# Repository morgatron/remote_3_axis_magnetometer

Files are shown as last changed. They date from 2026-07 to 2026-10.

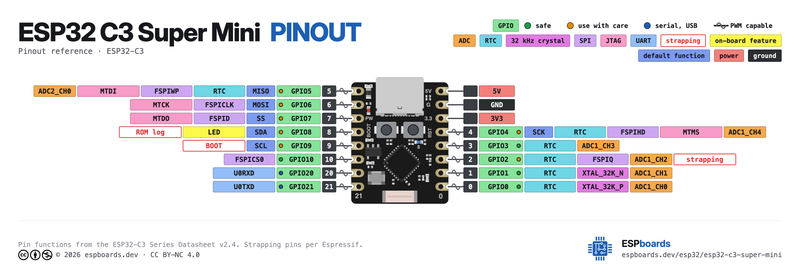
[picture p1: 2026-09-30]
docs/datasheets/supermini_diagram.png

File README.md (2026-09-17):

# Remote 3-Axis Magnetometer Acquisition System

A high-resolution, battery-powered remote magnetic field monitoring ecosystem supporting PNI RM3100 digital SPI magnetometers and FLC100 analog fluxgates (sampled via 24-bit TI ADS131E08 ADC).

Features universal field sensor firmware, multi-protocol receiver gateway firmware (**LoRa**, **ESP-NOW**, **BLE Coded PHY**, **WiFi UDP**), an edge relay service, a PySide6 desktop plotting app, and a central server with a real-time Web GUI dashboard.

---

## 📖 User Documentation

Complete user documentation is available in the [`docs/`](docs/) directory:

- [**Documentation Index (`docs/README.md`)**](docs/README.md)
- [**1. Getting Started Guide (`docs/1_GETTING_STARTED.md`)**](docs/1_GETTING_STARTED.md)
- [**2. Firmware & Power Optimization Guide (`docs/2_FIRMWARE_AND_POWER_GUIDE.md`)**](docs/2_FIRMWARE_AND_POWER_GUIDE.md)
- [**3. Wireless & Field Testing Guide (`docs/3_WIRELESS_AND_FIELD_TESTING.md`)**](docs/3_WIRELESS_AND_FIELD_TESTING.md)
- [**4. Central Server & Dashboards Guide (`docs/4_CENTRAL_SERVER_AND_DASHBOARDS.md`)**](docs/4_CENTRAL_SERVER_AND_DASHBOARDS.md)
- [**Active Device Profiles Reference (`IN_USE_PROFILES.md`)**](IN_USE_PROFILES.md)
- [**Minimal End-to-End Testing Setup (`TESTING_SETUP.md`)**](TESTING_SETUP.md)
- [**AI Architecture & Development Guide (`AI.md`)**](AI.md)

---

## 🚀 Quickstart

```bash
# 1. Clone & activate Conda environment
git clone https://github.com/morgatron/remote_3_axis_magnetometer.git
cd remote_3_axis_magnetometer
conda env create -f environment.yml
conda activate rm3100

# 2. Start Central Data Server
cd central_service && python server.py
# Open http://localhost:8000

# 3. Flash Heltec V4 Gateway Node
pio run -e heltec_v4_receiver -t upload --upload-port /dev/ttyACM1

# 4. Flash Heltec V4 Field Sensor Node
pio run -e heltec_v4_sensor -t upload --upload-port /dev/ttyACM0
```

---

## 🛠 Supported Hardware

| Hardware Board | Microcontroller | Radio Transceivers | Sensor Interfaces |
| :--- | :--- | :--- | :--- |
| **Heltec WiFi LoRa 32 V4** | ESP32-S3 (Dual-core LX7 @ 240 MHz) | Sub-GHz SX1262 LoRa (+22 dBm), Wi-Fi, BLE 5.0 | PNI RM3100 / ADS131E08 ADC |
| **ESP32-C6 RISC-V PCB** | ESP32-C6 (RISC-V @ 160 MHz) | Wi-Fi 6 (802.11ax), BLE 5.3 Coded PHY, 802.15.4 | PNI RM3100 / ADS131E08 ADC |
| **ESP32-C3 RISC-V PCB** | ESP32-C3 (RISC-V @ 160 MHz) | Wi-Fi 4, BLE 5.0 | PNI RM3100 / ADS131E08 ADC |

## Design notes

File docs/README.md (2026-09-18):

# Remote 3-Axis Magnetometer System — Documentation

Welcome to the documentation for the **Remote 3-Axis Magnetometer Acquisition System**.

---

## 📚 Core Manuals

1. [**1. Getting Started Guide**](1_GETTING_STARTED.md)
   - System architecture overview
   - Hardware pinouts & wiring (ESP32-C3 Supermini, Seeed XIAO ESP32-C6, Heltec V4, RM3100, FLC100)
   - PlatformIO build environments & flashing commands
   - Provisioning wizard (`provision_node.py` & `provision_receiver.py`)

2. [**2. Firmware & Power Optimization Guide**](2_FIRMWARE_AND_POWER_GUIDE.md)
   - Binary batching architecture (`SensorBatchPacket` with centi-degree temperature & $V_{bat}$)
   - Interactive Serial CLI command reference for Sensor and Receiver nodes
   - Multi-protocol output modes (BLE Coded PHY, LoRa SX1262, ESP-NOW, Wi-Fi UDP)
   - Low-power techniques (Slotted Rendezvous 350ms lead time, DFS 40MHz sleep, OLED auto-sleep)

3. [**3. Wireless & Field Testing Guide**](3_WIRELESS_AND_FIELD_TESTING.md)
   - Real-time phone monitoring using the **nRF Connect** app
   - Understanding signal strength: Sensor-to-Gateway RSSI vs. Gateway-to-Phone RSSI
   - Laptop Python client (`scripts/ble_monitor.py`) with real-time diagnostic decoding
   - Wireless range testing & link margin evaluation (`scripts/rssi_monitor.py`)

4. [**4. Central Server & Dashboards Guide**](4_CENTRAL_SERVER_AND_DASHBOARDS.md)
   - Self-contained FastAPI Central Server (`server.py`) and operations manager (`manage.sh`)
   - Docker Compose deployment & port mappings
   - REST API endpoints, WebSockets, API Key authentication, CSV & HDF5 export
   - Desktop PySide6 application (`desktop_app/main.py`)

---

## 📦 Legacy Archives
Older guides and historical references are preserved in [`docs/archive_legacy_docs/`](archive_legacy_docs/).

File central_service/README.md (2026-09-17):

# Magnetometer Central Service

A lightweight, future-proof time-series ingestion server, WebSockets live streaming hub, and real-time Web GUI dashboard for distributed 3-axis magnetometer sensor networks.

Designed to run seamlessly on **Raspberry Pi 4**, **Old Laptops (Linux/Ubuntu)**, or **Docker** behind residential home Wi-Fi networks (NAT/CGNAT).

---

## ⚡ Quick Start (1-Line Installer)

On your target machine (Raspberry Pi or Laptop):

```bash
cd central_service
sudo ./install.sh
```

The installer will:
1. Install Python packages & SQLite.
2. Configure `.env` settings.
3. Install and start `magnetometer-server` and `magnetometer-gateway` as auto-restarting **systemd background services**.
4. Apply hardware tweaks (disables laptop lid-close sleep and Wi-Fi power savings).
5. Print your local LAN access URLs (`http://192.168.x.x:8000`).

---

## 🛠️ Management CLI (`./manage.sh`)

Manage the server with intuitive commands:

```bash
./manage.sh status     # Show health, memory, database file size, and record count
./manage.sh logs       # Live stream colorized logs
./manage.sh restart    # Restart services
./manage.sh stop       # Stop services
./manage.sh backup     # Safe online SQLite backup into backups/
./manage.sh export csv # Quick CLI telemetry export to CSV (or parquet, npz)
./manage.sh test       # Inject synthetic test reading to verify the pipeline
```

---

## 🌐 Remote Access & Residential NAT / CGNAT (`./remote_access.sh`)

If your server sits behind a home Wi-Fi router with dynamic IPs or Carrier-Grade NAT (CGNAT), run the interactive assistant:

```bash
./remote_access.sh
```

- **Option 1 (Cloudflare Tunnels - Recommended)**: Outbound tunnel to Cloudflare Edge. Zero ports opened on router, free automatic SSL/HTTPS, and remote sensor nodes (ESP32/Pi) stream data with **zero VPN or client software required**.
- **Option 2 (Tailscale Mesh VPN)**: Private encrypted WireGuard mesh for administrative access between personal machines.
- **Option 3 (Port Forwarding & DDNS Guide)**: Traditional port forwarding walkthrough for non-CGNAT ISPs.
- **Option 4 (NAT / CGNAT Diagnostics)**: Check if your ISP uses CGNAT (`100.64.0.0/10`).

---

## 🐳 Docker Deployment

```bash
# Start server in background
docker compose up -d

# Start server + UDP edge gateway
docker compose --profile all up -d
```

---

## 📚 Detailed Documentation

- [Central Server & Dashboards Guide (`docs/4_CENTRAL_SERVER_AND_DASHBOARDS.md`)](../docs/4_CENTRAL_SERVER_AND_DASHBOARDS.md)
- [Central Server Architecture & API Specification (`central_service/AI.md`)](AI.md)
- [Historical Legacy Server Setup Guide (`docs/archive_legacy_docs/SERVER_SETUP_GUIDE.md`)](../docs/archive_legacy_docs/SERVER_SETUP_GUIDE.md)
- [Historical NAT & Remote Access Guide (`docs/archive_legacy_docs/NAT_AND_REMOTE_ACCESS.md`)](../docs/archive_legacy_docs/NAT_AND_REMOTE_ACCESS.md)
- [Historical Secrets & Security Guide (`docs/archive_legacy_docs/SECRETS_AND_SECURITY.md`)](../docs/archive_legacy_docs/SECRETS_AND_SECURITY.md)

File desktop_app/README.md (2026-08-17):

# 3-Axis Magnetometer Visualizer Desktop App

This PySide6 desktop application provides a modular, real-time visualization, PSD spectral analysis, and HDF5 scientific data acquisition platform for distributed 3-axis magnetometers.

## Prerequisites
- Python 3.8+ (included in the `rm3100` Conda environment)
- Microcontroller connected via USB Serial CDC or broadcasting over Wi-Fi UDP (Port 9876).

## Installation
```bash
cd desktop_app
pip install -r requirements.txt
```

## Usage
```bash
python main.py
```
1. Select the correct **Port** (e.g. `/dev/ttyACM0` or `WIFI_UDP (Port 9876)`).
   - Tip: Select `MOCK_SENSOR` to run in simulated mode without physical hardware.
2. Click **Connect**.
3. Use **Stream ON** / **Stream OFF** to control MCU streaming.
4. Switch to the **PSD Analysis** tab to view real-time Power Spectral Density.
5. Click **Provision Node...** to configure remote network and measurement parameters over Serial CLI.

## Modular Architecture

The desktop application is divided into self-contained, decoupled subsystems:

```
desktop_app/
├── main.py                  # Lightweight orchestrator MainWindow (< 300 lines)
├── core/
│   ├── data_buffer.py       # Thread-safe circular ring buffer with downsampling
│   └── hdf5_recorder.py     # Chunked Gzip-compressed HDF5 streaming recorder
├── widgets/
│   ├── time_series_plot.py  # PyQtGraph 3-axis plotting widget & real-time filters
│   ├── psd_plot.py          # Welch PSD spectral analysis widget
│   ├── stats_panel.py       # Real-time channel means display
│   ├── acquisition_sidebar.py # HDF5 recording & dynamic sensor controls
│   └── provision_dialog.py  # Modal dialog for ESP32 NVS provisioning
├── serial_worker.py         # Background serial reader thread
├── udp_worker.py            # Background UDP packet receiver thread
└── hdf5_loader.py           # Helper script for loading saved HDF5 files
```

## Loading Saved HDF5 Data

Saved acquisitions are stored in compressed scientific HDF5 (`.h5`):

```python
from hdf5_loader import load_hdf5_dataset

data, attrs = load_hdf5_dataset("acquisition.h5")
print(f"Loaded {len(data['time_s'])} samples recorded over {attrs.get('duration_seconds', 0):.2f}s")
print(f"X mean: {data['x'].mean():.2f} nT, Y mean: {data['y'].mean():.2f} nT, Z mean: {data['z'].mean():.2f} nT")
```

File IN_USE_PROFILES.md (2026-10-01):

The device profiles currently in use are the following, with labels to refer to them.
All use battery power unless specified otherwise

- Heltec V4 sensor (label: SPRINGBANK)
    - connected to FLC100.
    - transmits over LoRa only
- Heltec V4 Receiver (label: ROOF)
    - Receives over LoRa (SX1262 Sub-GHz, batches from SPRINGBANK)
    - Connects directly to campus enterprise Wi-Fi (ANU-Secure WPA2-Enterprise 802.1X PEAP or standard PSK)
    - Synchronizes atomic UTC time via NTP (pool.ntp.org) and reconstructs millisecond-accurate ISO 8601 sample timestamps
    - Egress: Direct HTTP POST JSON batch forwarding to Central Server (`/api/v1/telemetry/batch` with `X-API-Key`)
    - Concurrent USB Serial CDC output preserved for local monitoring and CLI configuration
    - wired power
- Seeed Studio Xiao ESP32-C6 Sensor (label: CREEK)
    - connected to FLC100
    - communicates over BLE with coded PHY
- Seeed Studio Xiao ESP32-C6 Sensor (label: CREEK_TEST)
    - connected to FLC100
    - communicates over BLE with coded PHY (node ID: _CREEK)
- Seed Studio Xiao ESP32-C6 (label: CREEK_GATEWAY)
    - Receives using BLE coded PHY only
    - relays data to host computer using BLE
- Supermini ESP32-C3 Receiver (label: SUPERMINI_GATEWAY)
    - Receives using BLE Coded PHY only (Slotted Rendezvous: 350 ms lead time, 1000 ms fallback window, immediate discovery lock)
    - Dedicated Coded PHY active scanning (`pScan->setPhy(SCAN_CODED)`) ensuring 100% duty cycle reception and instant `AUX_SCAN_REQ` hardware ACKs
    - Cadence tracking invariant to backlog (`nominalPeriod = 10000 ms`, never scales with `sample_count`)
    - Relays data to host computer using BLE Extended Advertising (1M PHY, 200 ms burst)
    - USB-CDC disabled on boot (`ARDUINO_USB_MODE=0`, `ARDUINO_USB_CDC_ON_BOOT=0`) for minimum quiescent power draw
    - Wi-Fi radio powered off (`WiFi.mode(WIFI_OFF)`, ~80 mA saved)
    - Dynamic Frequency Scaling (DFS): 40 MHz during radio sleep (~10–12 mA), 80 MHz during burst/RX
    - Target current: ~12 - 15 mA average (~65 - 80 hours on 1,000 mAh LiPo / ~8 - 10 days on 3,000 mAh 18650)
- Seeed Studio Xiao ESP32-C6 Sensor (label: LAB_BENCH)
    - connected to FLC100
    - wired USB power (used for lab bench magnetic measurements)
    - communicates with desktop GUI host computer over USB Serial only (`MODE SERIAL`, 921600 baud)
    - 100 Hz output streaming rate (1 kHz raw ADS131E08 ADC data downsampled by a factor of 10)
    - not for use with wireless gateway or central server (BLE/LoRa/WiFi radios disabled)
- Supermini ESP32-C3 Sensor (label: LYNEHAM1)
    - connected to RM3100 3-axis magneto-inductive sensor
    - Cycle count set to 600 on X, Y, Z (gain: 221.76 LSB/µT, resolution: 4.51 nT/LSB)
    - Continuous sampling at ~40 Hz (`TMRC 0x96`), downsampled 40x via boxcar averaging to 1.00 Hz
    - `I2CEN` held LOW via GPIO 5 virtual ground to force hardware SPI mode
    - wired USB power (plugs directly into host computer)
    - communicates with host computer over USB Serial only (`MODE SERIAL`, 921600 baud, 1 Hz CSV output)
    - not for use with wireless gateway or central server (BLE/LoRa/WiFi radios disabled)

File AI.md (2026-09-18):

# Overview

This repository contains firmware, an edge gateway, a PySide6 desktop visualization application, and a lightweight central data server (`central_service`) for an ESP32-based 3-axis magnetometer acquisition system.

A single universal firmware binary supports two sensor configurations via NVS dynamic provisioning:
1. **PNI RM3100**: High-resolution digital SPI magnetometer (Hardware REVID `0x22`).
2. **FLC-100 Analog Fluxgate Array**: Differential analog front-end sampled via an external **TI ADS131E08 24-bit 8-channel SPI ADC** (VREF = 2.4V, 2.0 MHz SPI clock).

The system streams calibrated 6-column magnetic field data in **Nanotesla (nT)** over Serial (921.6 kbaud), WiFi UDP (Port 9876), or Bluetooth 5.0 LE (Nordic UART Service) at up to **1 kSPS** (600 Hz max for RM3100).

---

## Key System Architecture Features

1. **MCU On-Board Scaling**:
   - The ESP32 calculates scale factors on-board: $\text{Gain}(N_C) = 0.3671 \times N_C + 1.5\ \text{LSB}/\mu\text{T}$.
   - Converting raw counts directly to physical Nanotesla ($\text{nT}$) before output ensures the reported magnitude $|\mathbf{B}|$ remains invariant across dynamic cycle count ($N_C \in [50, 400]$) and rate changes.

2. **Self-Healing Hardware Watchdog**:
   - Detects SPI bus stalls or missed `/DRDY` interrupts (e.g. from physical bumps or power glitches) within **500 ms**.
   - Automatically detaches interrupts, resets SPI CS pins, re-probes and re-initializes the sensor ASIC, clears hardware latches, and resumes streaming without requiring a manual reboot.

3. **Central Data Server (`central_service/`)**:
   - Single-file FastAPI + SQLite (WAL mode) time-series server designed for 10–50 distributed nodes on a Raspberry Pi (< 30 MB RAM).
   - Real-time Web GUI (`http://localhost:8000`) with live WebSockets (`/ws/live`).
   - Versioned API (`/api/v1/...`) with export support for **CSV**, **Apache Parquet (`.parquet`)**, **NumPy (`.npz`)**, and **JSON**.
   - Built-in server-side downsampling (`downsample_sec=60`) for multi-month trend analysis.

4. **Unified Edge Gateway (`central_service/gateway.py`)**:
   - Listens concurrently for WiFi UDP (port 9876), BLE 5.0 (Nordic UART Service), and USB Serial streams.
   - Includes a thread-safe **Store-and-Forward Buffer** to queue telemetry during network outages and flush batch payloads upon reconnection.

5. **PySide6 Desktop Application (`desktop_app/main.py`)**:
   - Provides real-time multi-axis time-series plotting, Welch PSD spectral analysis, device provisioning, and Gzip-compressed HDF5 (`.h5`) logging.

6. **Edge Arrival Timestamping & Monotonic Epoch Tracking (`NodeEpochTracker`)**:
   - Field nodes stream raw microsecond uptimes (`timestamp_us`) without requiring battery-backed RTC chips or NTP client stacks.
   - Upon packet arrival at the edge gateway (`gateway.py` / `ble_monitor.py`), `NodeEpochTracker` locks and tracks the node's monotonic boot epoch ($T_{\text{epoch}} = T_{\text{wall}} - t_{\mu\text{s}} \times 10^{-6}$) against the host's NTP-synchronized UTC clock.
   - For multi-sample batches and backlog recovery dumps after outages, `NodeEpochTracker` maps each sample's `timestamp_us` directly to its true historical UTC moment, preventing timestamp clustering or collisions during high-speed backlog catch-up bursts while smoothly filtering microsecond crystal frequency drift (~15 ppm).

7. **Modular Telemetry Ring Buffer (`include/TelemetryRingBuffer.h`)**:
   - Encapsulates 10-minute (600-sample) disconnect backlog storage into a thread-safe, self-contained C++ class.
   - Automatically handles FIFO eviction during prolonged outages, batch packaging for Coded PHY BLE Extended Advertising bursts, and hardware `AUX_SCAN_REQ` ACK confirmation flushes.
   - Standardized across all target boards on **NimBLE-Arduino 2.2.0** for BLE 5.0 Long Range Coded PHY support.

8. **Unified Multi-Protocol Receiver Interface (`src/receiver/ITelemetryReceiver.h`)**:
   - Abstracts all physical receiver drivers (`BLEReceiver`, `ESPNowReceiver`, `UDPReceiver`, `LoRaReceiver`) behind a polymorphic `ITelemetryReceiver` interface.
   - Decouples receiver initialization (`begin()`) and non-blocking polling (`poll()`) from the main loop thread, ensuring zero-blocking execution (< 25 $\mu$s per tick).
   - Centralizes CSV formatting (`formatCsvLine()`) and string parsing (`parseCsvLine()`) directly inside `TelemetryItem` to eliminate code duplication across protocols.

---

---

## Hardware Management Architecture (`include/board_config.h` & `platformio.ini`)

All hardware target boards are managed through a **centralized, single-source-of-truth configuration design**:

1. **Centralized Board Header (`include/board_config.h`)**:
   - Maps MCU preprocessor macros to physical board pinouts (Magnetometer SPI, LoRa SPI, status LEDs, and power rails).
   - Provides `initBoardPower()` to control hardware power gating rails (e.g. driving Heltec Vext GPIO 36 `LOW` during setup).
   - Abstracts hardware differences away from firmware business logic (`main.cpp` and `receiver_main.cpp`).

2. **DRY PlatformIO Configuration (`platformio.ini`)**:
   - Root `[env]` base section defines common parameters (`framework = arduino`, `monitor_speed = 921600`, upload flags, and native USB CDC defines).
   - Target environments inherit from `[env]` and select their role via `build_src_filter`:
     - **Field Sensor Node**: `build_src_filter = +<*> -<receiver/*>`
     - **Receiver & Gateway Node**: `build_src_filter = +<receiver/*>`

### Supported Hardware Pinout Reference Table

| Target Hardware Board | PlatformIO Env (`Sensor` / `Receiver`) | Sensor SCK | Sensor MOSI | Sensor MISO | Sensor CS | Sensor DRDY | LoRa CS / DIO1 / RST / BUSY | Vext Rail |
| :--- | :--- | :--- | :--- | :--- | :--- | :--- | :--- | :--- |
| **ESP32-C3 RISC-V PCB** | `esp32-c3-devkitm-1` / `esp32c3_receiver` | GPIO 6 | GPIO 7 | GPIO 2 | GPIO 10 | GPIO 3 | GPIO 5 / 4 / 14 / 15 | N/A |
| **ESP32-C6 Wi-Fi 6 PCB** | `esp32-c6-devkitc-1` / `esp32c6_receiver` | GPIO 6 | GPIO 7 | GPIO 2 | GPIO 10 | GPIO 3 | GPIO 5 / 4 / 14 / 15 | N/A |
| **Heltec V4 (ESP32-S3 + SX1262)** | `heltec_v4_sensor` / `heltec_v4_receiver` | GPIO 41 | GPIO 42 | GPIO 40 | GPIO 39 | GPIO 38 | GPIO 8 / 14 / 12 / 13 | GPIO 36 |
| **Legacy ESP32 Dev (WROOM)** | `esp32dev` / `esp32dev_receiver` [Deprecated] | GPIO 18 | GPIO 23 | GPIO 19 | GPIO 5 | GPIO 4 | GPIO 5 / 4 / 14 / 15 | N/A |

### How to Add a New Hardware Board
To support a new board (e.g. ESP32-S3 DevKit or Raspberry Pi Pico 2 W):
1. Add a `#elif defined(YOUR_BOARD)` block in [`include/board_config.h`](file:///home/morgan/Gropbox/SMACT2026/remote_3_axis_magnetometer/include/board_config.h) defining SPI CS, SCK, MOSI, MISO, DRDY, and LoRa pins.
2. Add sensor and receiver target environment blocks in [`platformio.ini`](file:///home/morgan/Gropbox/SMACT2026/remote_3_axis_magnetometer/platformio.ini) with `-D YOUR_BOARD`.

---

## Data Stream Format & CLI Reference

### 6-Column CSV Data Stream
`device_id,timestamp_us,x_nT,y_nT,z_nT,status`
- **`device_id`**: Node identifier string (e.g. `SENSOR_01` or MAC-derived `NODE_686F80`).
- **`timestamp_us`**: MCU uptime in microseconds (`uint64_t`).
- **`x_nT, y_nT, z_nT`**: Calibrated 3-axis magnetic field in Nanotesla ($\text{nT}$).
- **`status`**: 24-bit hex SPI status word (e.g., `C00000`).

### Interactive CLI Commands (Serial / UDP / BLE)

| Command | Description |
| :--- | :--- |
| `HELP` / `STATUS` | Display CLI help / Query Device ID, sensor model, rate code, BLE batch size, and status |
| `STREAM ON` / `OFF` | Enable / disable continuous telemetry stream |
| `ID <name>` | Configure custom Device ID / Node name (saves to NVS Flash) |
| `SENSOR <FLC100\|RM3100\|MOCK>` | Set active sensor model (`MOCK` = synthetic range test telemetry) |
| `RATE <hex>` | Set rate code (`0x95` = 75 Hz, `0x94` = 150 Hz, `0x93` = 300 Hz, `0x92` = 600 Hz) |
| `CYCLE <int>` | Set RM3100 oscillation cycle count (e.g. `CYCLE 200`) |
| `BATCH <1-10>` | Set BLE burst size (`1` = instant 1 Hz, `10` = 10s low-power mode; saved to NVS) |
| `MODE <SERIAL\|WIFI\|BLE\|BOTH>` | Route stream to USB Serial, WiFi UDP, BLE Long Range, or both |

---

## Low-Power LE Coded PHY Batching & Hardware ACK Architecture (Primary Mode)

> [!IMPORTANT]
> **Canonical Primary Protocol Constraint**: The **Low-Power Bluetooth 5.0 LE Coded PHY Batching Protocol with Hardware ACKs and Disconnect Ring Buffering** is the canonical primary operational mode for field sensor nodes. Future edits MUST preserve this low-power ACK architecture.

1. **BLE 5.0 LE Coded PHY (Long Range S=8)**:
   - Extended Advertising using **Coded PHY S=8 (125 kbps)** provides **+12 dB sensitivity gain** (~4x range multiplier over standard BLE) at **+15 dBm Max Power**.

2. **Configurable Batch Bursting (`BATCH <1-10>`)**:
   - The BLE radio remains **100% OFF for 9.7 seconds** out of every 10 seconds (`BATCH 10`).
   - At burst time, `pAdvertising->start(0, 30)` powers on the radio for **300 ms** (30 x 10ms units) to broadcast a 139-byte Extended Advertising payload (`SensorBatchPacket`) containing up to 10 compact 3-axis samples over Coded PHY S=8.
   - **Transmission-Complete Auto-Stop**: When the 300ms burst completes, the `onStopped` hardware callback fires, setting `g_lastBatchAcked = true` and powering **OFF** the radio until the next 10-second window.
   - **RF Duty Cycle**: Reduces active RF transmission duty cycle to **< 0.5%**, extending battery life to **35–45 days** on a 1000 mAh LiPo.

3. **Hardware `AUX_SCAN_REQ` ACKs & 10-Minute Disconnect Ring Buffer**:
   - **Zero-Power Hardware ACKs**: Uses native Bluetooth 5.0 `AUX_SCAN_REQ` hardware scan request frames sent by the gateway upon receiving a burst (`onScanRequest` and `onStopped` callbacks).
   - **10-Minute Offline Buffer**: If the gateway goes out of range or offline, the sensor node retains up to **600 samples (10 Minutes of data)** in SRAM (~7.2 KB).
   - **Catch-up Flushing**: Once the gateway is back in range, the sensor node receives hardware ACKs and rapidly flushes the backlog in consecutive 300ms bursts until `unackedCount` returns to 0.
   - **Sensor Reboot Recovery**: Upon sensor reset, uptime timestamps restart near 0 ms. The Receiver `NodeTracker` detects `start_ts_ms < node.last_sample_ts_ms`, resetting `last_batch_start_ts_ms = 0xFFFFFFFF` to accept post-reset bursts continuously without stale timestamp deadlocks.
   - **Canonical Node Prefix Filtering**: Rejects non-sensor BLE devices by enforcing `NODE_*`, `MOCK_*`, and `MAG_*` device ID prefixes in `isValidBatchPacket` and `isValidSensorPacket`.
   - **Receiver OLED Telemetry Refresh**: Automatically refreshes `lastOledActivityMs = millis()` whenever valid telemetry packets arrive, keeping the OLED screen awake and updating while telemetry flows.

4. **Dynamic Frequency Scaling (DFS) Power Management**:
   - Configured with `min_freq = 20MHz`, `max_freq = 160MHz`, and `light_sleep_enable = false`.
   - **Why Light Sleep was disabled**: Automatic Light Sleep powers down the main 80 MHz APB bus clock and PLL. Re-locking the PLL incurs **1.5–3.0 ms of wake latency**, causing severe `DRDY` interrupt jitter and **sample loss** at 75 Hz sampling.
   - Keeping the APB clock powered ON (`light_sleep_enable = false`) guarantees **sub-microsecond (< 1 µs) interrupt latency with 0% sample loss**, while DFS throttles idle CPU power to 20 MHz (~3.5 mA system current).

5. **Low-Power Gateway Receiver Optimizations**:
   - **Dynamic Frequency Scaling (DFS)**: Automatically throttles CPU from 80 MHz down to **40 MHz** (`setCpuFrequencyMhz(40)`) during the 8.5-second radio-off sleep window once egress broadcast completes, cutting baseline MCU power by >50% without dropping baseband registers or incurring wake jitter. Dynamically restores CPU to 80 MHz with 400ms lead time before the next scheduled burst.
   - **30-Second OLED Auto-Sleep**: Display controller sleeps after 30s of inactivity (~20 mA savings); wakes instantly via the **PRG / USER button (GPIO 0)** or Serial CLI input.
   - **Smart Wi-Fi Off**: Automatically turns off Wi-Fi radio when operating in USB Serial Egress mode (`MODE SERIAL`) or connectionless BLE mode (`MODE BLE`), saving ~80 mA.

---

## ESP32 Multi-Protocol Receiver & Data Relay Firmware (`src/receiver/`)

An ESP32 configured as a dedicated field receiver/relay ingests telemetry from battery-powered remote sensors across multiple wireless radio interfaces concurrently and forwards data to the host computer / central server.

### Key Receiver Features
1. **Multi-Protocol Wireless Ingestion**:
   - **Slotted Rendezvous BLE Coded PHY Receiver**: Tracks remote node transmission burst periods, dynamically calculates sleep intervals, and powers OFF the BLE radio between bursts (~98.6% radio sleep duty cycle), waking with a 400ms lead time to capture incoming bursts in ~100–150ms.
   - **ESP-NOW**: Ultra-low power, fast connectionless MAC-layer protocol (handles binary struct `SensorBinaryPacket` and string CSV payloads).
   - **BLE / BLE Coded PHY**: Bluetooth 5 Long Range advertisement observer.
   - **WiFi UDP**: Listens on UDP port 9876 for field sensor broadcast packets.
2. **Triple Egress Relay**:
   - **USB Serial (CDC)**: Output formatted CSV stream at 921,600 baud directly to `gateway.py` or host PC.
   - **BLE 1Mbps Connectionless Extended Advertising**: Broadcasts telemetry bursts using BLE 5 Extended Advertising Auxiliary PDUs (up to 18 samples per packet, company ID `0xFFFF`, magic `b"MG"`). 100% connectionless, no GATT handshakes, pairing, or supervision timeouts.
   - **WiFi Egress**: Forwards batched payloads to Central Server HTTP endpoint or target UDP IP.
3. **Active Node Tracking**:
   - In-memory Node Table (`NODES` command) tracks device IDs, MAC addresses, RSSI signal strength, packet counts, last-seen timestamps, battery voltages, and ambient temperatures.

### Receiver CLI Commands
| Command | Description |
| :--- | :--- |
| `HELP` / `STATUS` | Display receiver status, protocol packet counts, DFS clock, and network info |
| `NODES` | Print real-time table of all active remote sensor nodes with RSSI & Vbat |
| `MODE <SERIAL\|WIFI\|BOTH\|BLE>` | Select egress relay destination (USB Serial, WiFi Network, Both, or BLE Connectionless) |
| `DEBUG [ON\|OFF]` | Toggle BLE rendezvous and discovery debug logging |
| `DFS [ON\|OFF]` | Toggle Dynamic Frequency Scaling (40MHz sleep / 80MHz burst) |
| `WIFI <ssid> <pass>` | Save egress router credentials and connect to WiFi |
| `TARGET <ip> [port]` | Configure target Central Server IP and port for WiFi forwarding |
| `CHANNEL <1-13>` | Set ESP-NOW WiFi radio channel |
| `SAVE` | Persist current configuration to NVS Flash memory |
| `REBOOT` | Restart receiver MCU |

### Slotted Rendezvous & Low-Power Gateway Architectural Rules & Gotchas

> [!IMPORTANT]
> **Slotted Rendezvous Constraints (SUPERMINI_GATEWAY & C6 Receivers)**:
> The following rules are critical to maintaining sub-15 mA average gateway power and drift-free synchronization with field sensors:
>
> 1. **Cadence Tracking Invariance to Backlog (`NodeTracker.cpp`)**:
>    - **NEVER scale `nominalPeriod` by `sample_count`** (e.g. `sample_count * 1000`).
>    - *Rationale*: Field sensor nodes operate on a strict 10.0-second transmission grid (`minBurstIntervalMs = 10000`). When a sensor drains un-ACKed backlog, `sample_count` dynamically increases up to 18 samples, but the burst interval remains strictly 10.0s. Scaling `nominalPeriod` causes the receiver to project an 18-second sleep, completely missing the sensor and breaking sync.
>    - `nominalPeriod` is fixed at 10,000 ms with an adaptive acceptance window of 7,500 ms – 12,500 ms (±25% crystal tolerance). The measured interval $dt$ is smoothed via EWMA: $(3 \times \text{period} + dt) / 4$.
>
> 2. **Immediate Discovery Lock & Transition to Sleep (`RendezvousScheduler.cpp`)**:
>    - When entering `STATE_DISCOVERY` (on boot or after 3 consecutive missed windows), the scheduler must **immediately exit Discovery upon the first valid batch reception** (`IngestionPipeline::getLastBatchRxMs() >= _stateStartMs`).
>    - *Rationale*: Blindly waiting for the full 12.0s discovery timeout wastes up to 11 seconds of continuous ~75 mA radio scanning and causes the receiver to exit Discovery out-of-phase with the sensor. Exiting immediately anchors `_nextWakeMs` to the exact burst arrival timestamp and drops power to ~10 mA within milliseconds.
>
> 3. **Lead Time Margin vs Uncalibrated Crystal Drift (`RendezvousScheduler.h`)**:
>    - `LEAD_TIME_MS` must be at least **350 ms**.
>    - *Rationale*: Low-cost ESP32-C3 internal oscillators / crystals can deviate by 2–3% (e.g. 9,730 ms instead of 10,000 ms = 270 ms early). On cold boot, before EWMA has measured the true interval, a 250 ms lead time causes the sensor to transmit ~20 ms *before* the receiver wakes up. A 350 ms lead time guarantees the receiver is awake ~80 ms ahead of the burst. Since the receiver shuts down the radio within ~5 ms of packet arrival, extra lead time incurs zero power penalty once synchronized.
>
> 4. **Dedicated Coded PHY Scanning (`BLEReceiver.cpp`)**:
>    - Must explicitly call `pScan->setPhy(NimBLEScan::Phy::SCAN_CODED)` during radio setup.
>    - *Rationale*: NimBLE-Arduino defaults to `SCAN_ALL` (0x03), splitting scan time 50/50 between 1M and Coded PHY. This causes missed bursts and dropped hardware `AUX_SCAN_REQ` ACKs on Coded PHY.
>
> 5. **Bluetooth Controller Power-Gating (`BLEReceiver.cpp` & `PowerManager.cpp`)**:
>    - MUST call `NimBLEDevice::deinit(false)` and `esp_bt_controller_disable()` during periodic slotted rendezvous sleep.
>    - *Rationale*: On the ESP32-C3, `pScan->stop()` only halts the NimBLE scan task at the host layer; the underlying hardware Bluetooth controller (`esp_bt_controller`), baseband modem, and RF PLL synthesizer remain fully clocked and powered, drawing ~21–22 mA continuously. Disabling the controller cuts sleep current from 32 mA down to 10–12 mA at 40 MHz CPU. Reinitializing NimBLE takes only ~10–15 ms, easily absorbed by the 350 ms lead margin. *(Bench-verified on hardware meter: current drops cleanly to 10 mA with 100% burst ACKs maintained across wakeups).*
>
> 6. **Headless Battery Operation & USB-CDC (`platformio.ini`)**:
>    - On the `SUPERMINI_GATEWAY` receiver profile, USB CDC is disabled on boot (`ARDUINO_USB_MODE=0`, `ARDUINO_USB_CDC_ON_BOOT=0`) to eliminate USB PLL power draw.
>    - Diagnostics (heartbeats, window misses, discovery locks) are broadcast over 1M Extended Advertising (`BLEEgress::broadcastDiagnostic`), allowing full headless debugging via `scripts/ble_monitor.py`.

---

## Running & Testing

> [!TIP]
> For step-by-step testing guides:
> - **Low-Power BLE Coded PHY Mock Testing**: See [`docs/simple_ble_testing_setup.md`](file:///home/morgan/Gropbox/SMACT2026/remote_3_axis_magnetometer/docs/simple_ble_testing_setup.md).
> - **Full System Hardware Pipeline Setup**: See [`TESTING_SETUP.md`](file:///home/morgan/Gropbox/SMACT2026/remote_3_axis_magnetometer/TESTING_SETUP.md).

### Conda Environment Setup
```bash
conda env create -f environment.yml
conda activate rm3100
```

### Firmware Build & Flash

```bash
# 1. Field Sensor Node Firmware (ESP32-C3 PCB)
pio run -e esp32-c3-devkitm-1 -t upload --upload-port /dev/ttyACM0

# 2. Field Sensor Node Firmware (ESP32-C6 Wi-Fi 6 / 802.15.4)
pio run -e esp32-c6-devkitc-1 -t upload --upload-port /dev/ttyACM0

# 3. Field Sensor Node Firmware (Heltec V4 ESP32-S3 + SX1262 LoRa)
pio run -e heltec_v4_sensor -t upload --upload-port /dev/ttyACM0

# 4. Multi-Protocol Receiver & Gateway (ESP32-C6 Wi-Fi 6)
pio run -e esp32c6_receiver -t upload --upload-port /dev/ttyACM1

# 5. Multi-Protocol Receiver & Gateway (Heltec V4 ESP32-S3 + SX1262 LoRa)
pio run -e heltec_v4_receiver -t upload --upload-port /dev/ttyACM1

# 6. Provision Field Sensor Node via Serial CLI
python3 scripts/provision_node.py -c provision_config.json --port /dev/ttyACM1

# 7. Provision Gateway Receiver Node via Serial CLI
python3 scripts/provision_receiver.py -c provision_receiver_config.json --port /dev/ttyACM0

# 8. Automated Heltec V4 LoRa Setup & Over-The-Air Test Tool (AU915 Band)
python3 scripts/setup_lora_test.py --sensor-port /dev/ttyACM1 --rcvr-port /dev/ttyACM0
```

### Central Data Server & Web GUI

```bash
cd central_service

# Optional: Set API_KEY for secure open-internet deployment
export API_KEY="my_secret_key_123"
python server.py
# Open http://localhost:8000
```

#### API Key Authentication Setup

To secure the server against unauthorized open-internet data injection:

1. **Server Configuration**: Set `export API_KEY="your_secret_key"` before launching `server.py`.
   - When `API_KEY` is set, all state-mutating requests (`POST /api/v1/telemetry`, `POST /api/v1/telemetry/batch`, `POST /api/v1/nodes/update`) require the HTTP header `X-API-Key: your_secret_key`.
   - If `API_KEY` is not set or empty, authentication is disabled for local offline debugging.
   - Read-only endpoints (`GET /`, `GET /health`, `GET /api/v1/nodes`, `GET /api/v1/data`) remain open so dashboards can display telemetry without authentication.

2. **Gateway Configuration**: Set matching `export API_KEY="your_secret_key"` before running `gateway.py`:
   ```bash
   export API_KEY="your_secret_key"
   export CENTRAL_SERVER_URL="http://localhost:8000"
   python3 central_service/gateway.py
   ```

#### Web GUI Features

- **Signal Strength (RSSI) Plotting**: Real-time signal strength (in $\text{dBm}$) is stored in the database, displayed on each node card, and selectable in the field dropdown.
- **Historical Time-Range Selector**: Choose between **Live Stream**, **Last 1 Hour** (10s avg), **Last 6 Hours** (1m avg), **Last 24 Hours** (1m avg), or **Last 7 Days** (1h avg) to analyze database trends directly in the browser.
- **Multi-Node Overlay Plotting**: Select **Overlay: All Nodes** ($|B|$, $B_z$, or $\text{RSSI}$) to plot multiple field nodes simultaneously on a single chart with distinct color-coded lines for spatial gradient comparison.

### Run Automated Test Suite

```bash
# 1. Run Complete Automated Test Suite (Single Command)
python3 scripts/run_all_tests.py

# Or run individual test suites:
python3 test/test_batch_serialization.py
python3 test/test_receiver_parser.py
python3 test/test_scaling_math.py
python3 central_service/test_server.py

# 2. Standalone Hardware Self-Tests (Requires connected hardware)
python3 test/test_sensor_standalone.py --port /dev/ttyACM1
python3 test/test_receiver_standalone.py --port /dev/ttyACM0
python3 test/test_cycle_count_invariance.py --port /dev/ttyACM1

# 3. End-to-End Multi-Device Integration Test (Sensor + Receiver)
python3 test/test_integration_sensor_receiver.py --sensor-port /dev/ttyACM1 --rcvr-port /dev/ttyACM0
```

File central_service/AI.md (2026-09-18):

# Magnetometer Central Data Server & Gateway Services (`central_service`)

## Overview

The `central_service` is a future-proof, lightweight, Raspberry Pi-friendly central data ingestion, edge gateway, and monitoring platform designed for long-term time-series recording of distributed 3-axis magnetometer networks (10 to 50 nodes operating at ~1 Hz down to 1 sample/minute).

Built with **FastAPI** and **SQLite** (WAL mode), it operates with zero heavy database setup and minimal memory footprint (< 30 MB RAM).

---

## API v1 & Data Schema Future-Proofing

1. **Database Schema Stability (`magnetometer.db`)**:
   - `telemetry`: `timestamp`, `node_id`, `x`, `y`, `z`, `units` ('nT'), `temp`, `vbat`, `rssi`, `status_flags`, `extra_json`.
   - `nodes`: `node_id`, `name`, `lat`, `lon`, `elevation_m`, `last_seen`, `sensor_model`, `cycle_count`, `baseline_x`, `baseline_y`, `baseline_z`, `notes`.
   - **Automatic Safe Migrations**: `init_db()` automatically runs non-destructive `ALTER TABLE ADD COLUMN` checks on startup, ensuring past SQLite database files remain 100% compatible.

2. **API Versioning & Forward Compatibility**:
   - Primary REST endpoints are versioned under `/api/v1/...` (`/api/v1/telemetry`, `/api/v1/telemetry/batch`, `/api/v1/data`, `/api/v1/nodes`).
   - Legacy routes (`/api/telemetry`, `/api/data`, `/api/nodes`) are maintained as permanent alias routes for 100% backward compatibility.

3. **Data Export Formats**:
   - **CSV (`.csv`)**: Standardized headers (`timestamp_utc`, `node_id`, `x_nT`, `y_nT`, `z_nT`, `magnitude_nT`, `temp_c`, `vbat_mv`).
   - **Apache Parquet (`.parquet`)**: Ultra-fast, compressed columnar binary format for scientific data.
   - **NumPy Compressed (`.npz`)**: Native array export for Python (`x_nT`, `y_nT`, `z_nT`, `magnitude_nT`).
   - **JSON**: Structured REST responses with `schema_version: "1.0"`.

4. **Server-Side Downsampling**:
   - Use `downsample_sec=60` (1-min) or `3600` (1-hour) on `/api/v1/data` to query multi-month datasets at high speeds.

5. **Edge Arrival Timestamping & Monotonic Epoch Tracking (`NodeEpochTracker`)**:
   - Microcontrollers stream raw microsecond uptimes (`timestamp_us`) without requiring battery-backed RTCs or NTP client code.
   - Upon arrival at `gateway.py` / `ble_monitor.py`, `NodeEpochTracker` locks each node's boot epoch ($T_{\text{epoch}} = T_{\text{wall}} - t_{\mu\text{s}} \times 10^{-6}$) against the host's system UTC clock.
   - When an outage ends and the ring buffer dumps historical backlog, `NodeEpochTracker` places each sample at its true historical UTC moment, preventing timestamp clustering or collisions while filtering out crystal oscillator frequency drift (~15 ppm). Node reboots are detected automatically to re-anchor a fresh boot epoch.

---

## Open-Internet Security & API Key Authentication

To secure the server against unauthorized open-internet data injection:

1. **Server Configuration**: Set `export API_KEY="your_secret_key"` before launching `server.py`.
   - All state mutation endpoints (`POST /api/v1/telemetry`, `POST /api/v1/telemetry/batch`, `POST /api/v1/nodes/update`) automatically require `X-API-Key: your_secret_key` in the request header.
   - If `API_KEY` is omitted or empty, authentication is disabled for local offline testing.
   - Read-only endpoints (`GET /`, `GET /health`, `GET /api/v1/nodes`, `GET /api/v1/data`) remain open so dashboards can display telemetry without authentication.

2. **Gateway Configuration**: Set matching `export API_KEY="your_secret_key"` before running `gateway.py`:
   ```bash
   export API_KEY="your_secret_key"
   export CENTRAL_SERVER_URL="http://192.168.1.100:8000"
   python gateway.py
   ```

---

## Web GUI Dashboard Features (`static/index.html`)

- **Signal Strength (RSSI) Plotting**: Real-time signal strength (in $\text{dBm}$) is stored in the database, displayed on each node card, and selectable in the field dropdown.
- **Historical Time-Range Selector**: Select **Live Stream**, **Last 1 Hour** (10s avg), **Last 6 Hours** (1m avg), **Last 24 Hours** (1m avg), or **Last 7 Days** (1h avg) to analyze database trends directly in the browser.
- **Multi-Node Overlay Plotting**: Select **Overlay: All Nodes** ($|B|$, $B_z$, or $\text{RSSI}$) to plot multiple field nodes simultaneously on a single chart with distinct color-coded lines for spatial gradient comparison.

---

## File Structure

```
central_service/
├── install.sh                # Automated one-click installer for Raspberry Pi 4 & Linux Laptops
├── manage.sh                 # Unified operations CLI (status, start, stop, restart, logs, backup, export)
├── remote_access.sh          # Residential NAT assistant (Tailscale, Cloudflare Tunnels, CGNAT check)
├── server.py                 # FastAPI + SQLite backend server & WebSocket hub (.env supported)
├── gateway.py                # Unified UDP, BLE, and Serial store-and-forward edge gateway
├── stream_parser.py          # Shared parsing logic for MCU telemetry lines & microsecond delta-t batches
├── static/
│   └── index.html            # Real-time web GUI monitoring dashboard
├── systemd/                  # Systemd service templates for 24/7 background operation
│   ├── magnetometer-server.service
│   └── magnetometer-gateway.service
├── .env.example              # Environment variables template (ports, paths, API keys)
├── client_example.py         # Future-proof Python script loading data into Pandas/NumPy/Parquet
├── test_server.py            # Automated end-to-end HTTP test suite
├── test_simulator.py         # Multi-node simulator for testing 1 Hz telemetry & magnetic transients
├── requirements.txt          # Python dependencies
├── docker-compose.yml        # Docker Compose configuration (server + gateway profiles)
└── Dockerfile                # Lightweight Python container setup with healthcheck
```

---

## Quick Start & Deployment

### Method 1: Automated Installer (Raspberry Pi 4 / Laptop) - Recommended
```bash
cd central_service
sudo ./install.sh
```
This automatically sets up Python virtual environments, systemd auto-restart services, laptop lid-close behavior, and SD card safety.

### Method 2: Management Script (`manage.sh`)
```bash
./manage.sh status     # Check health, database size, memory, and telemetry count
./manage.sh logs       # Live stream logs
./manage.sh backup     # Safe online SQLite backup
./manage.sh export csv # Quick CLI export
```

### Method 3: Running Behind Residential NAT / CGNAT
```bash
./remote_access.sh     # Interactive assistant for Cloudflare Tunnels (Recommended) & NAT diagnostics
```

### Method 4: Docker Compose
```bash
docker compose up -d                  # Server only
docker compose --profile all up -d    # Server + UDP Gateway
```

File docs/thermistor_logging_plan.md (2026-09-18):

# Implementation Plan: ADC Channel 4 Thermistor Logging (CREEK)

> [!NOTE]
> **Status: FULLY IMPLEMENTED & LIVE IN FIRMWARE**
> Thermistor logging on ADC Channel 4 is fully integrated across `FLC100_ADS131`, `TelemetryPacket.h` (`temp_c_x100`), `IngestionPipeline`, `RelayEgress`, and `scripts/ble_monitor.py`. This document is preserved as the hardware specification and Steinhart-Hart equation reference.

## 1. Overview & Objectives
On the CREEK sensor board (FLC100 3-Axis Fluxgate Carrier with TI ADS131E08 24-bit ADC), an NTC thermistor is wired to **ADC Channel 4**. 

Magnetic fluxgate sensors exhibit temperature-dependent offset drift (typically $\approx 0.5 \text{ to } 1.5\text{ nT}/^\circ\text{C}$). Logging board temperature enables calibration and thermal drift compensation.

### Key Requirements
- **Low Cadence**: Temperature changes slowly (thermal inertia of board/sensors). Sampling once every 10 seconds (or once per batch burst) is sufficient.
- **Zero RF & SPI Waste**: Clocks out Channel 4 within the existing ADS131E08 frame without extra SPI transactions. Encodes temperature in only 2 bytes in the batch header.
- **Pipeline Integration**: Ingestion pipeline (`IngestionPipeline.cpp`) already defines `item.temp` (currently defaulted to `0.0f`). This plan populates that field with real temperature data.

---

## 2. Hardware Architecture & ADC Mechanics

### ADS131E08 Channel Mapping
The ADS131E08 clocks out 27 bytes per DRDY frame (3 status bytes + 8 channels $\times$ 3 bytes):
```
[Byte 0..2]   : Status Word (24 bits, e.g. 0xC00000)
[Byte 3..5]   : CH1 (X-axis fluxgate)
[Byte 6..8]   : CH2 (Y-axis fluxgate)
[Byte 9..11]  : CH3 (Z-axis fluxgate)
[Byte 12..14] : CH4 (NTC Thermistor Divider)  <-- TARGET
[Byte 15..26] : CH5 to CH8 (Unused, powered down)
```

- **Current State**: `CH4SET` is written to `0x81` (Channel powered down, inputs shorted internally).
- **Proposed State**: Configure `CH4SET` to `0x10` (Channel powered on, Gain = 1, normal electrode input).
- **SPI Overhead**: **0 additional SPI bytes** and **0 additional interrupt latency** because the 27-byte transaction already transfers all 8 channel slots.

---

## 3. Protocol & Data Structure Specifications

### A. `SensorBatchPacket` (`include/TelemetryPacket.h`)
Add `int16_t temp_c_x100` (centi-degrees Celsius, e.g., `2350` = $23.50\,^\circ\text{C}$, `0x7FFF` = invalid/unmeasured) immediately after `vbat_mv`:

```cpp
typedef struct __attribute__((packed)) {
    char          device_id[8];         // Null-terminated identifier (e.g. "CREEK")
    uint32_t      latest_sample_age_ms; // Age in ms of newest sample at TX
    uint16_t      sample_interval_ms;   // Time between samples (e.g. 1000 ms = 1 Hz)
    uint8_t       sample_count;         // Number of samples in batch (up to 18)
    uint16_t      status;               // Status word
    uint16_t      vbat_mv;              // Battery voltage in mV
    int16_t       temp_c_x100;          // Temperature in centi-deg C (2 bytes) <-- NEW
    CompactSample samples[18];          // Array of up to 18 compact samples
} SensorBatchPacket;
```
- **Packet Size**: Increases header from 19 bytes to 21 bytes (+2 bytes). Total packet size for 10 samples increases from 139 bytes to 141 bytes (well below the 251-byte Extended Advertising limit).

### B. `GatewayAdvPacket` (`include/TelemetryPacket.h`)
Update the gateway re-broadcast packet to include `temp_c_x100`:
```cpp
typedef struct __attribute__((packed)) {
    uint16_t      company_id;           // 0xFFFF
    uint8_t       magic[2];             // 0x4D, 0x47 ("MG")
    uint8_t       packet_seq;           // Transmission sequence counter
    char          node_id[8];           // Field node identifier
    uint64_t      timestamp_us;         // Microsecond timestamp
    uint16_t      sample_interval_ms;   // Sample interval in ms
    uint8_t       sample_count;         // Number of samples in packet
    uint16_t      status;               // Status word
    uint16_t      vbat_mv;              // Battery voltage in mV
    int16_t       temp_c_x100;          // Temperature in centi-deg C (2 bytes) <-- NEW
    int8_t        rssi;                 // Signal strength in dBm
    CompactSample samples[18];          // Samples array
} GatewayAdvPacket;
```

---

## 4. Thermistor Mathematics (Beta Equation)

### Circuit Topology (Voltage Divider)
Assuming an NTC thermistor in a divider configuration:
- Reference Voltage: $V_{ref} = 2.40\text{ V}$ (or $V_{cc} = 3.3\text{ V}$)
- Bias Resistor: $R_b = 10.0\text{ k}\Omega$
- Thermistor Nominal: $R_0 = 10.0\text{ k}\Omega$ at $T_0 = 298.15\text{ K}$ ($25.0\,^\circ\text{C}$)
- Thermistor Beta: $B \approx 3950\text{ K}$ (configurable)

### Calculation Steps
1. **Raw ADC to Voltage**:
   $$\text{rawCH4} = (\text{buffer}[12] \ll 16) \mid (\text{buffer}[13] \ll 8) \mid \text{buffer}[14]$$
   Sign-extend 24-bit two's complement to 32-bit `int32_t`.
   $$V_{ch4} = \frac{\text{rawCH4} \times V_{ref}}{2^{23} \times \text{Gain}}$$

2. **Voltage to Resistance** (for high-side NTC, low-side $R_b$):
   $$R_{ntc} = R_b \times \left(\frac{V_{ref}}{V_{ch4}} - 1.0\right)$$
   *(Note: verify whether NTC is on high or low side of the carrier board divider).*

3. **Resistance to Temperature ($\beta$ parameter model)**:
   $$\frac{1}{T} = \frac{1}{T_0} + \frac{1}{B} \ln\left(\frac{R_{ntc}}{R_0}\right)$$
   $$T_C = T - 273.15$$
   $$\text{temp\_c\_x100} = \text{(int16\_t)}\text{roundf}(T_C \times 100.0\text{f})$$

---

## 5. Required Code Modifications

### 1. `lib/FLC100_ADS131/FLC100_ADS131.h` & `.cpp`
- In `begin()`:
  Configure `ADS131_REG_CH4SET` with `0x10` (Gain 1, Normal input). Only power down channels 5 through 8 (`0x81`).
- In `readAndPushSample()`:
  Save the latest raw 24-bit reading of Channel 4 into a member variable `_lastRawCh4`.
- Add getter method:
  `int32_t getLatestChannel4Raw();` or `float readTemperatureC();`

### 2. `src/main.cpp`
- In `checkBleBurstTransmission()`:
  When preparing `SensorBatchPacket batch`:
  ```cpp
  if (sensor && sensorTypeConfig == 1) {
      float tC = static_cast<FLC100_ADS131*>(sensor)->readTemperatureC();
      batch.temp_c_x100 = (int16_t)roundf(tC * 100.0f);
  } else {
      batch.temp_c_x100 = 0x7FFF; // Sentinel: invalid/not supported
  }
  ```

### 3. `src/receiver/IngestionPipeline.cpp`
- In `ingestBatch()`:
  Replace hardcoded `item.temp = 0.0f;` with:
  ```cpp
  if (batch.temp_c_x100 != 0x7FFF) {
      item.temp = (float)batch.temp_c_x100 / 100.0f;
  } else {
      item.temp = 0.0f;
  }
  ```
- The existing CSV output formatter automatically outputs the real temperature in the 7th column:
  `CREEK,2161000,-8415.58,-27382.00,5845.43,004D4F,23.50,4.03,-52`

### 4. `src/receiver/BLEReceiver.cpp`
- Ensure `minBatchSize` calculation uses updated `sizeof(SensorBatchPacket)`.

---

## 6. Implementation & Verification Steps (When Ready)
1. **Confirm Schematic**: Check PCB schematic for thermistor divider orientation (high side vs low side) and resistor values ($R_b$, $R_0$, $B$).
2. **Apply Firmware Changes**: Update packet definitions, ADC driver, burst assembler, and receiver pipeline.
3. **Flash Both Devices**:
   - `esp32-c6-devkitc-1` on `/dev/ttyACM1` (CREEK)
   - `esp32c3_receiver` on `/dev/ttyACM0` (SUPERMINI_GATEWAY)
4. **Verification**:
   - Observe Gateway CSV stream: 7th column should reflect ambient temperature (e.g. `~22.0` to `~26.0` °C).
   - Place a warm finger on the PCB thermistor and verify temperature increases in real time.

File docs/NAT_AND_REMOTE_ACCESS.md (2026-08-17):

# Running Behind a Residential NAT & Remote Access Guide

In a residential home setting, your server (Raspberry Pi 4, laptop, or mini-PC) sits behind a home Wi-Fi router. The router assigns a private local IP address (e.g. `192.168.1.100`) using Network Address Translation (NAT) or Carrier-Grade NAT (CGNAT).

This guide explains how to make your central data server securely accessible to remote field sensor nodes (ESP32 / Pi gateways) and web browsers worldwide **without opening router ports, with zero client-side VPN software required**.

---

## 1. Executive Summary: Why Cloudflare Tunnels is the Recommended Route

For a distributed sensor network with field nodes and multi-user web monitoring, **Cloudflare Tunnels (`cloudflared`)** is the primary recommended solution:

```
[ Field Sensor Node ] ---- HTTPS POST (Open Internet) ----+
(ESP32 / 4G Gateway)                                      |
                                                          v
[ Web Dashboard User ] --- HTTPS GET (Browser / Phone) -> [ Cloudflare Edge Network ]
                                                          |
                                           (Encrypted Outbound Tunnel)
                                                          v
                                                  [ cloudflared daemon ]
                                                  [ Central Data Server ] (Pi 4 / Laptop)
                                                  (Behind Residential NAT / CGNAT)
```

### Key Advantages:
1. **Zero Client-Side Software**: Remote field nodes (ESP32 microcontrollers, field Raspberry Pis, cellular relays) and web users connect via standard HTTPS URLs (e.g., `https://mag.yourdomain.com`). They do **not** need VPN apps, WireGuard, or client certificates.
2. **Zero Router Configuration**: The server establishes an outbound encrypted QUIC/HTTP2 tunnel to Cloudflare. You do **not** need to open or forward ports on your home router.
3. **100% CGNAT & Dynamic IP Immune**: Works behind residential ISPs, Carrier-Grade NAT (`100.64.0.0/10`), 4G/5G home internet, and dynamic residential public IPs.
4. **Free Automatic SSL/TLS**: Cloudflare provisions and auto-renews valid TLS certificates.
5. **DDoS Protection & Authentication**: Built-in rate limiting, optional Cloudflare Zero Trust authentication (Google/email PIN), and API key ingestion security.

---

## 2. Cloudflare Account & Domain Setup (Step-by-Step)

Setting up Cloudflare Tunnels is 100% free (including unlimited tunnel bandwidth).

### Step 1: Create a Free Cloudflare Account
1. Go to [dash.cloudflare.com/sign-up](https://dash.cloudflare.com/sign-up).
2. Enter your email and choose a password.
3. Choose the **Free Plan** ($0/month).

### Step 2: Add or Purchase a Domain
You need a domain name to route traffic (e.g., `yourdomain.com` or `sensor-station.org`):

- **Option A: Use an Existing Domain (Recommended if you already own one)**:
  1. In Cloudflare Dashboard, click **Add a Domain**.
  2. Select the **Free Plan**.
  3. Cloudflare will scan your DNS and provide two nameservers (e.g., `bob.ns.cloudflare.com`, `lisa.ns.cloudflare.com`).
  4. Log in to your domain registrar (Namecheap, GoDaddy, Porkbun, Google/Squarespace, etc.) and update the domain's Custom Nameservers to Cloudflare's.
  5. Wait a few minutes for verification.
- **Option B: Purchase a New Domain via Cloudflare Registrar**:
  - In Cloudflare Dashboard, go to **Domain Registration** -> **Register Domains**.
  - Domains cost at-cost wholesale pricing ($9–$10/year for `.com`, `.org`, etc.) with zero markup and free WHOIS privacy.
- **Option C: Zero-Account Instant Test Link (`trycloudflare`)**:
  - If you just want to test immediately without signing up for an account or domain, see **Section 3 (Mode C)** below.

---

## 3. Creating & Running the Cloudflare Tunnel

There are two primary ways to set up the tunnel:

### Mode A: Web Dashboard & Token Setup (Easiest — 1 Copy-Paste Command)

1. In the Cloudflare Dashboard, navigate to **Zero Trust** (or go to [one.dash.cloudflare.com](https://one.dash.cloudflare.com/)).
2. Under **Networks**, click **Tunnels**.
3. Click **Create a Tunnel** -> Select **Cloudflared** connector -> Click **Next**.
4. Name your tunnel (e.g. `magnetometer-central`).
5. Cloudflare will show an installation command with your unique **Tunnel Token**, for example:
   ```bash
   sudo cloudflared service install eyJhIjoi...
   ```
6. On your server machine (Pi or Laptop), either:
   - Run `./remote_access.sh` -> Select **Option 1 -> Token Setup** and paste the token, or
   - Run the displayed `sudo cloudflared service install <TOKEN>` command directly.
7. Click **Next** in the Cloudflare Dashboard.
8. Configure the **Public Hostname**:
   - **Subdomain**: `mag` (or `data`)
   - **Domain**: `yourdomain.com`
   - **Path**: *(leave empty)*
   - **Type**: `HTTP`
   - **URL**: `localhost:8000`
9. Click **Save Tunnel**.

**Done!** Your server is now accessible worldwide at `https://mag.yourdomain.com`.

---

### Mode B: CLI Setup (Command Line Only)

If you prefer configuring via SSH terminal:

1. Run the interactive assistant:
   ```bash
   cd central_service
   ./remote_access.sh
   # Select Option 1 -> (3) CLI-based Tunnel Setup
   ```
2. Or perform manually:
   ```bash
   # 1. Authenticate with Cloudflare
   cloudflared tunnel login

   # 2. Create named tunnel
   cloudflared tunnel create magnetometer

   # 3. Route your DNS hostname
   cloudflared tunnel route dns magnetometer mag.yourdomain.com

   # 4. Create config file ~/.cloudflared/config.yml
   cat <<EOF > ~/.cloudflared/config.yml
   tunnel: magnetometer
   credentials-file: /home/$USER/.cloudflared/magnetometer.json

   ingress:
     - hostname: mag.yourdomain.com
       service: http://localhost:8000
     - service: http_status:404
   EOF

   # 5. Install as systemd service
   sudo cloudflared service install
   sudo systemctl start cloudflared
   ```

---

### Mode C: Instant 1-Click Test Link (No Account or Domain Needed)

For quick field testing or temporary live sharing:

```bash
cd central_service
./remote_access.sh
# Select Option 1 -> (1) Quick Instant Test Link
```
Or directly:
```bash
cloudflared tunnel --url http://localhost:8000
```
This generates a temporary public HTTPS link (e.g. `https://random-words.trycloudflare.com`) in seconds.

---

## 4. Securing Ingestion & Remote Sensor Node Configuration

> [!TIP]
> For a deep dive on key generation, restricted file permissions (`chmod 600`), and ESP32 hardware flash encryption, see the dedicated [**Secrets Management & System Security Guide**](SECRETS_AND_SECURITY.md).

### Step 1: Enable Server API Key Authentication
To prevent unauthorized parties on the open internet from submitting fraudulent telemetry, set an `API_KEY` in `central_service/.env`:

```ini
# central_service/.env
API_KEY="your_secure_random_token_here_12345"
```
Restart the server to apply:
```bash
./manage.sh restart
```

- When `API_KEY` is set, all write requests (`POST /api/v1/telemetry`, `POST /api/v1/telemetry/batch`, `POST /api/v1/nodes/update`) require the `X-API-Key: your_secure_random_token_here_12345` header.
- Read-only endpoints (`GET /`, `GET /health`, `GET /api/v1/data`) remain open for browser viewing.

### Step 2: Configure Remote Gateways / ESP32 Nodes
On your remote field gateways:
```bash
export CENTRAL_SERVER_URL="https://mag.yourdomain.com"
export API_KEY="your_secure_random_token_here_12345"
python gateway.py
```
For standalone ESP32 WiFi nodes sending HTTP POSTs directly:
- Destination URL: `https://mag.yourdomain.com/api/v1/telemetry`
- Header: `X-API-Key: your_secure_random_token_here_12345`

### Step 3: (Optional) Cloudflare Zero Trust Access for Web GUI
If you wish to restrict the browser Web GUI to authorized users:
1. In Cloudflare Zero Trust Dashboard, go to **Access** -> **Applications** -> **Add an application** -> **Self-hosted**.
2. Set Domain to `mag.yourdomain.com`.
3. Add a Policy requiring your email or a Google/GitHub login.
4. Add a Bypass rule or Service Token for path `/api/v1/telemetry*` so field sensor nodes can continue sending data without user login.

---

## 5. Alternative Options Comparison

| Criteria | Cloudflare Tunnels (Recommended) | Tailscale Mesh VPN | Router Port Forwarding |
| :--- | :--- | :--- | :--- |
| **Primary Use Case** | Distributed sensor nodes & public/team web access | Private admin access between personal machines | Traditional self-hosting (non-CGNAT) |
| **Client Software Needed?** | **No** (Standard HTTPS for all clients) | **Yes** (Tailscale client on every device) | **No** |
| **ESP32 Microcontroller Compatible?** | **Yes** (Standard HTTP/HTTPS POST) | **No** (ESP32 cannot run Tailscale) | **Yes** |
| **Bypasses CGNAT / NAT?** | **Yes (100%)** | **Yes (100%)** | **No** |
| **Requires Open Router Ports?** | **No (0 ports opened)** | **No** | **Yes** (Port 8000/443 forwarded) |
| **SSL/HTTPS Encryption** | Automatic Cloudflare TLS | Automatic Tailscale TLS | Requires manual Caddy/Certbot |
| **Setup Time** | 3 Minutes | 2 Minutes | 15 Minutes |

---

## 6. Summary Quick Reference

To configure remote access at any time:
```bash
cd central_service
./remote_access.sh
```
Follow the interactive prompt to install the Cloudflare Tunnel service and begin streaming telemetry from anywhere in the world.

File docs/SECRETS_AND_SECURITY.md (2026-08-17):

# Secrets Management & System Security Guide

This guide outlines security practices and secret-storage strategies across all tiers of the **Remote 3-Axis Magnetometer Acquisition System**, covering:
1. **Central Server Secrets (`API_KEY`)**
2. **Cloudflare Tunnel Tokens (`cloudflared`)**
3. **Remote Edge Gateways (`gateway.py`)**
4. **Embedded Microcontrollers (ESP32 Sensor Nodes & Receivers)**
5. **Git Hygiene & Leak Prevention**

---

## 1. Central Server Secrets (`API_KEY`)

The central data server uses an `API_KEY` to authenticate data-mutating requests (`POST /api/v1/telemetry`, `POST /api/v1/nodes/update`) while keeping dashboard reads open to authorized users.

### Best Practices:

1. **Generate High-Entropy Cryptographic Keys**:
   Avoid human-chosen passwords. Generate a random 256-bit key:
   ```bash
   # Using OpenSSL:
   openssl rand -hex 32

   # Or using Python:
   python3 -c "import secrets; print(secrets.token_urlsafe(32))"
   ```

2. **Restrict File Permissions (`chmod 600`)**:
   Store the key in `central_service/.env` and lock permissions so that only the service owner/root can read it:
   ```bash
   chmod 600 central_service/.env
   ```

3. **Systemd `EnvironmentFile` Isolation**:
   The systemd service unit (`magnetometer-server.service`) loads `EnvironmentFile=-%WORKING_DIR%/.env`. Systemd injects these variables directly into the process environment in memory, preventing secrets from appearing in process listings (`ps aux`).

---

## 2. Cloudflare Tunnel Token (`cloudflared`)

### Understanding the Token:
- The Cloudflare Tunnel token generated by Cloudflare Zero Trust is an **ephemeral connector secret** scoped *strictly* to establishing the outbound QUIC reverse tunnel for that specific Tunnel ID.
- It **cannot** be used to log into your Cloudflare dashboard, modify DNS records, or access billing.

### Storage & Protection:
1. **Systemd Root Storage**:
   When you install the tunnel using `sudo cloudflared service install <TOKEN>` (or via `central_service/remote_access.sh`), the token is written to `/etc/cloudflared/config.yml` owned by `root:root` with permissions `0600`.
2. **Named Tunnel Credentials**:
   If configuring named tunnels manually, Cloudflare creates a JSON credentials file `~/.cloudflared/<tunnel-id>.json`. This directory is ignored in `.gitignore` and must never be committed to Git.

---

## 3. Remote Edge Gateways & Python Clients (`gateway.py`)

For remote Raspberry Pis deployed in the field running `gateway.py`:

1. **Dedicated Client Configuration**:
   Store the server URL and API key in a local `.env` file on the field gateway:
   ```ini
   CENTRAL_SERVER_URL=https://mag.yourdomain.com
   API_KEY=your_secure_random_token
   ```
   Set permissions: `chmod 600 .env`.

2. **Scoped / Per-Site Keys (Multi-Site Deployments)**:
   For fleets of gateways across multiple locations, assign unique API keys per site. If a single field laptop or Pi is lost or compromised, you can revoke only that site's key without needing to re-provision the rest of the fleet.

---

## 4. Embedded Microcontrollers (ESP32 Sensor Nodes & Receivers)

Microcontrollers in the field are physically exposed, making secret storage a distinct challenge.

```
+-------------------------------------------------------------------------------+
| ESP32 Secrets Storage Hierarchy                                              |
|                                                                               |
| Level 1: Hardcoded #define (Avoid)   --> Secrets baked into compiled binary   |
| Level 2: Dynamic NVS (Recommended)  --> Flashed via USB CLI; no code secrets |
| Level 3: NVS + Flash Encryption     --> Hardware AES key burned in eFuses    |
+-------------------------------------------------------------------------------+
```

### Level 1: Avoid Hardcoding Credentials in Source Code (Anti-Pattern)
- **Do NOT** define Wi-Fi passwords or API keys in `#define` macros or C++ source files.
- Hardcoded strings are easily leaked via public Git commits or extracted from `.bin` firmware dumps using string inspection tools.

### Level 2: Dynamic NVS Storage (Current System Architecture)
- Firmware source code contains **zero credentials**.
- Nodes boot in unprovisioned mode until configured.
- Credentials (`WIFI_SSID`, `WIFI_PASS`, `TARGET_IP`, `API_KEY`) are injected over USB UART using `scripts/provision_node.py` or the interactive Serial CLI (`WIFI <ssid> <pass>`, `TARGET <ip> <port>`).
- Credentials are saved in the ESP32's internal **Non-Volatile Storage (NVS)** partition in flash memory.

### Level 3: Hardware Flash & NVS Encryption (High-Security Outdoor Deployments)
If sensor nodes are deployed in unattended outdoor or public locations where physical theft is a possibility:
- **ESP32-S3 and ESP32-C6** support **Hardware Flash Encryption (AES-XTS-256)** and **NVS Encryption**.
- An encryption key is generated and burned into write-protected hardware **eFuses** (`BLOCK_KEY0`).
- Even if an attacker physically desolders the SPI flash chip and reads it with an external programmer, all NVS contents (Wi-Fi passwords and API keys) appear as encrypted pseudorandom data.

---

## 5. Git Hygiene & Leak Prevention

| Practice | Details |
| :--- | :--- |
| **Strict `.gitignore`** | `.env`, `.env.*`, `*.cfg`, `provision_config.json`, `provision_receiver_config.json`, `.cloudflared/`, and `*.token` are strictly ignored. |
| **Commit Only Template Files** | Always commit template files with placeholders (e.g. `central_service/.env.example`, `provision_config.example.json`, `provision_receiver_config.example.json`). |
| **Pre-Commit Scanners** | For shared/public repositories, install `git-secrets` or `trufflehog` to scan for high-entropy strings and block accidental commits containing credentials. |

---

## 6. Summary Checklist

- [ ] `central_service/.env` created and set to `chmod 600`.
- [ ] Generated a 256-bit random string for `API_KEY`.
- [ ] Cloudflare Tunnel token installed via `remote_access.sh` (stored under `/etc/cloudflared/`).
- [ ] Field nodes configured dynamically via NVS provisioning (`provision_node.py`); no hardcoded Wi-Fi passwords in C++.
- [ ] `.gitignore` verified to exclude local config files and credentials.

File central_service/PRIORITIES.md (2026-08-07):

# Priorities for the central service:
- Simple to understand
- simple for users to access data subsets and use with known tools (e.g. python, numpy)
- lightweight
- Support for a modest number of nodes: maybe 10, 50 at most.
- Analysis is not a priority - users can do their own analysis for now.
- Keep the nodes simple

# Network architecthure
- The central data server will likely run on a raspberry pi, in which case it should be easily installable
- The exact connectivity of each node is not entirely clear. Curently nodes will likely use Wifi or BT LE to transmit data back to a base, internet connected device (potentially another ESP32). The base is what will send the data to the central server.
    - A LoRa connected device is also possible

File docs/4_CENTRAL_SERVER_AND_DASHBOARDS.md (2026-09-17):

# 4. Central Server & Dashboards Guide

This guide covers running the self-contained FastAPI Central Server, managing Docker containers, accessing live dashboards, and using the Desktop PyQt5 application.

---

## 1. Quick Start: Managing the Central Server (`manage.sh`)

The central service is managed using the unified [`central_service/manage.sh`](file:///home/morgan/Gropbox/SMACT2026/remote_3_axis_magnetometer/central_service/manage.sh) script:

```bash
cd central_service

# Check service and database status
./manage.sh status

# Start Central Server in background
./manage.sh start

# Follow live server logs
./manage.sh logs -f

# Stop server
./manage.sh stop

# Create SQLite database backup
./manage.sh backup

# Vacuum and optimize SQLite database indices
./manage.sh vacuum
```

---

## 2. Docker Deployment

To launch the server via Docker Compose:

```bash
cd central_service
docker compose up -d

# Check health
docker compose ps
```

The container automatically exposes:
* **Port 8000:** FastAPI REST API, WebSockets, and Web UI.
* **Port 9876 (UDP):** Direct background packet listener for Wi-Fi sensor nodes.

---

## 3. REST API & WebSocket Endpoints

| Endpoint | Method | Description |
| :--- | :--- | :--- |
| `/` | `GET` | Interactive HTML/JS Web Dashboard with real-time vector graphs |
| `/api/v1/telemetry` | `POST` | Ingest single telemetry point |
| `/api/v1/telemetry/batch` | `POST` | Ingest 10-sample batch payload |
| `/api/v1/nodes` | `GET` | List active sensor nodes and their last-seen status |
| `/api/v1/query` | `GET` | Query time-series telemetry with time/node filters |
| `/api/v1/export/csv` | `GET` | Stream CSV data export |
| `/api/v1/export/hdf5` | `GET` | Stream HDF5 scientific data container |
| `/ws/live` | `WebSocket` | Real-time WebSocket telemetry broadcast |
| `/health` | `GET` | System health check and database statistics |

---

## 4. API Key Security (Optional)

To secure the server when exposed on an external network:
```bash
# On server:
export API_KEY="your_secure_passphrase"
./manage.sh start

# In gateway / clients:
export API_KEY="your_secure_passphrase"
python3 gateway.py
```
When set, write endpoints (`/api/v1/telemetry`, `/api/v1/telemetry/batch`) require the `X-API-Key` HTTP header. Read-only endpoints (`/`, `/health`, `/ws/live`) remain open for dashboards.

---

## 5. Desktop PySide6 Application (`desktop_app/`)

For lab testing and direct USB/UDP recording to HDF5:

```bash
cd desktop_app
pip install -r requirements.txt
python3 main.py
```

Features:
* Live high-speed 3-axis vector plotting ($B_x, B_y, B_z, |B|$).
* Real-time Welch Power Spectral Density (PSD) calculation.
* Direct serial capture from `/dev/ttyACM*`.
* Instant recording to standard `.h5` / `.npy` format.

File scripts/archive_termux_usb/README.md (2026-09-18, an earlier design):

# Legacy Termux USB-OTG Scripts Archive

This directory contains early prototypes for reading serial data over physical USB-OTG cables on Android phones running Termux.

These scripts have been superseded by the wireless **Bluetooth 5.0 LE Coded PHY $\to$ 1 Mbps BLE Gateway** architecture, which allows wireless field monitoring directly via the **nRF Connect** app or `scripts/ble_monitor.py`.

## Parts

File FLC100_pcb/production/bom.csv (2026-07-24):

Designator | Footprint | Quantity | Value | LCSC Part #
C1, C10, C15, C16, C17, C18, C19, C20, C21, C22, C23, C5, C7, C8 | 0603 | 14 | 1uF
C2, C24, C25, C26, C27, C28, C29, C30, C31, C32, C33, C9 | 0603 | 12 | 10uF
C3 | 0603 | 1 | 2.2uF
C4, C6 | 0402 | 2 | 100nF
H1, H2, H3 | HDR-TH_5P-P2.54-H-M-W10.4 | 3 | PZ254R-11-05P | C492413
H4 | HDR-TH_12P-P2.54-H-M-R2-C6-S2.54 | 1 | PZ254R-12-12P | C492434
L1 | IND-SMD_L4.0-W4.0 | 1 | SWPA4012S1R8NT | C96867
LED1, LED2, LED3, LED4 | LED0603-R-RD_WHITE | 4 | 0603White light_C2290 | C2290
R1, R2, R3, R4 | 0603 | 4 | 680
R10, R11, R12, R13, R14, R15 | 0805 | 6 | 100
R17 | R0603 | 1 | 0603WAF3001T5E | C4211
R18, R5 | 0402 | 2 | 10k
R6, R7, R8, R9 | 0805 | 4 | 100k
REF_5V1 | SOIC-8_L4.9-W3.9-P1.27-LS6.0-BL | 1 | ADR4525BRZ-R7 | C403914
SW2, SW3, SW4, SW5 | SW-SMD_2P-L3.5-W6.1-P2.54-LS9.8 | 4 | DSIC01LS-P_C600988 | C600988
U1 | LQFP-64_L10.0-W10.0-P0.50-LS12.0-TL | 1 | ADS131E08IPAGR | C190276
U10, U2 | CONN-TH_DB125-2.54-2P-GN | 2 | DB125-2.54-2P-GN | C918120
U4 | SOT-563-6_L1.6-W1.2-P0.50-LS1.6-BL | 1 | TPS61299DRLR | C41689719
U5 | SOT-23-5_L2.9-W1.6-P0.95-LS2.8-BR | 1 | TPS7A2050PDBVR | C2864504
U6, U7, U8, U9 | HDR-TH_14P-P2.54-V-F-2 | 4 | PM2.54-YP1D-14A | C22399554

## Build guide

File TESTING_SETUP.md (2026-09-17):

# Minimal End-to-End Testing & Deployment Guide (`TESTING_SETUP.md`)

This guide provides step-by-step instructions for setting up, deploying, and verifying a minimal end-to-end telemetry pipeline for the 3-Axis Magnetometer Acquisition System.

```
 +------------------------+      Wireless Radio       +--------------------------+     USB Serial / WiFi     +-------------------------+
 |   Field Sensor Node    |  -----------------------> |    ESP32 Receiver Node   |  -----------------------> |   Central Data Server   |
 | (Heltec V4 / ESP32-C6) | (LoRa / ESP-NOW / BLE / UDP)| (Heltec V4 / ESP32-C6) |    (gateway.py / HTTP)    | (http://localhost:8000) |
 +------------------------+                           +--------------------------+                           +-------------------------+
```

---

## 1. Start the Central Data Server

On your host computer or Raspberry Pi:

```bash
cd central_service
python server.py
```

- **Verification**: Open `http://localhost:8000` in your web browser. You will see the real-time Web GUI dashboard and WebSocket time-series plot.

---

## 2. Flash & Configure the Gateway Receiver Node

Flash an ESP32 board (e.g. Heltec V4 or ESP32-C6) with the dedicated receiver/relay firmware:

```bash
# Heltec V4 Receiver (ESP32-S3 + SX1262 LoRa)
pio run -e heltec_v4_receiver -t upload --upload-port /dev/ttyACM1

# Or ESP32-C6 Receiver (Wi-Fi 6 + BLE Coded PHY + ESP-NOW)
pio run -e esp32c6_receiver -t upload --upload-port /dev/ttyACM1

# Or ESP32-C3 Receiver PCB
pio run -e esp32c3_receiver -t upload --upload-port /dev/ttyACM1
```

### Egress Forwarding Options
- **USB Serial CDC (Default)**: Keep the gateway plugged into USB-C. It streams formatted CSV lines over USB Serial (921,600 baud) directly to the host PC running `gateway.py`.
- **WiFi Network Forwarding (Optional)**: Open Serial Monitor (`pio device monitor -b 921600`) and type:
  ```text
  WIFI <YourSSID> <YourPassword>
  TARGET <CentralServerIP> 9876
  MODE BOTH
  SAVE
  ```

---

## 3. Launch the Edge Gateway Relay Service

If your Gateway Receiver Node is connected to your host machine via USB:

```bash
cd central_service
python gateway.py
```

- `gateway.py` automatically reads USB Serial streams (`/dev/ttyACM1` / `/dev/ttyUSB1`) as well as WiFi UDP broadcasts on port 9876, and posts batched payloads to `http://localhost:8000/api/v1/telemetry/batch`.

---

## 4. Flash & Deploy Field Sensor Node(s)

Flash your remote battery-powered sensor board (connected to an RM3100 SPI magnetometer or FLC100/ADS131E08 ADC):

```bash
# Heltec V4 Field Sensor Node (ESP32-S3 + SX1262 LoRa)
pio run -e heltec_v4_sensor -t upload --upload-port /dev/ttyACM0

# Or ESP32-C6 Field Sensor Node (Wi-Fi 6 / 802.15.4)
pio run -e esp32-c6-devkitc-1 -t upload --upload-port /dev/ttyACM0

# Or ESP32-C3 Field Sensor Node PCB
pio run -e esp32-c3-devkitm-1 -t upload --upload-port /dev/ttyACM0
```

- **Auto-Detection**: The sensor node auto-probes the connected sensor hardware (RM3100 REVID `0x22` or ADS131E08 ADC) and streams calibrated physical Nanotesla ($\text{nT}$) data over sub-GHz LoRa, ESP-NOW, BLE, or WiFi UDP.

---

## 5. Verify Telemetry & Active Node Metrics

1. **Receiver CLI Node Table**: Open serial monitor on the Gateway Node (`pio device monitor -b 921600`) and type:
   ```text
   NODES
   ```
   You will see a real-time table of active remote nodes with MAC address, protocol source, RSSI signal strength (dBm), packet count, last seen timestamp, and battery voltage ($V_{bat}$).

2. **Central Web GUI**: Open `http://localhost:8000` to view live magnetic field vectors ($B_x, B_y, B_z$) and real-time PSD spectrum plots.

3. **Protocol-Specific Test Guides**:
   - For Wireless & Field Range Testing (BLE Coded PHY & LoRa): See [**Wireless & Field Testing Guide (`docs/3_WIRELESS_AND_FIELD_TESTING.md`)**](docs/3_WIRELESS_AND_FIELD_TESTING.md).
   - For Low-Power Modes & Timing Margins: See [**Firmware & Power Optimization Guide (`docs/2_FIRMWARE_AND_POWER_GUIDE.md`)**](docs/2_FIRMWARE_AND_POWER_GUIDE.md).

4. **Automated Host Test Suite (No Hardware Required)**:
   To test the software pipeline without physical hardware:
   ```bash
   # 1. Test Receiver Payload Parser & Microsecond Delta-t Reconstruction
   python test/test_receiver_parser.py

   # 2. Test 139-byte Batch Serialization & Sub-nT Float Packing
   python test/test_batch_serialization.py

   # 3. Test Central Server API Endpoints & Data Export Formats
   python central_service/test_server.py
   ```

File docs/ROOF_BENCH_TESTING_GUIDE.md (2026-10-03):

# ROOF Heltec V4 Gateway & SPRINGBANK LoRa Benchtop Testing Guide

This guide provides step-by-step instructions for bench testing, provisioning, and verifying the **ROOF** gateway receiver (Heltec V4 ESP32-S3 + SX1262 LoRa) and **SPRINGBANK** sensor pair, including WPA2-Enterprise (`ANU-Secure`) Wi-Fi, atomic NTP time synchronization, and HTTP batch forwarding to the Central Data Server.

---

## 1. System Architecture

```
[SPRINGBANK Sensor Node]
  - Heltec V4 (ESP32-S3 + SX1262 LoRa)
  - FLC100 3-Axis Fluxgate Magnetometer
  - 1 Hz Continuous Sampling, 10s Burst Interval (10 samples / burst)
       │
       ▼ (LoRa 915 MHz / Sub-GHz RF Burst)
[ROOF Gateway Node]
  - Heltec V4 (ESP32-S3 + SX1262 LoRa)
  - SX1262 Radio in Continuous RX Mode
  - Background NTP Client (pool.ntp.org)
  - Reconstructs sample ages into absolute millisecond UTC ISO 8601 timestamps
       │
       ├────────────────────────────────────────┬────────────────────────────────────────┐
       ▼ (HTTP POST /api/v1/telemetry/batch)    ▼ (Concurrent USB Serial CDC @ 921600)  ▼ (OLED Display)
[Central Data Server]                     [Host PC Serial Terminal]               Live Status & Counts
  - FastAPI + SQLite WAL Mode               - Real-time CSV logging & CLI
  - WebSocket Live Stream Broadcast
```

---

## 2. Prerequisites

1. **Hardware**:
   * 1x Heltec WiFi LoRa 32 V4 board for **ROOF** receiver gateway.
   * 1x Heltec WiFi LoRa 32 V4 board for **SPRINGBANK** sensor (or run `scripts/mock_roof_batch_sender.py` for server-only testing).
   * 915 MHz antennas connected to the SMA/IPEX ports on **both** Heltec boards before powering on (prevent RF amplifier damage).
   * USB-C data cables connecting boards to the host computer.
2. **Software Environment**:
   * Conda environment `rm3100` activated:
     ```bash
     conda activate rm3100
     ```
   * PlatformIO installed (`platformio --version` >= 6.1.0).

---

## 3. Step 1: Flashing the Firmware

### A. Flash the ROOF Receiver Gateway
Plug the receiver board into the host computer (identifies typically as `/dev/ttyACM0` or `/dev/ttyUSB0` on Linux):
```bash
pio run -e heltec_v4_receiver -t upload
```

### B. Flash the SPRINGBANK Sensor Node
Plug the sensor node into the host computer:
```bash
pio run -e heltec_v4_sensor -t upload
```

---

## 4. Step 2: Provisioning the ROOF Gateway via Serial CLI

Open a serial terminal connected to the **ROOF** receiver at **921600 baud**:
```bash
pio device monitor -b 921600
# Or using minicom / screen:
# minicom -D /dev/ttyACM0 -b 921600
```

Press `ENTER` or type `HELP` to view the CLI menu.

### 1. Check Device MAC Address
If device MAC registration is required by network administrators:
```text
MAC
```
*Output:*
```text
[WIFI] Station MAC: 34:85:18:XX:XX:XX
```

### 2. Configure Wi-Fi Credentials
Choose **one** of the following options based on your test environment:

#### Option A: ANU-Secure Enterprise Wi-Fi (WPA2-Enterprise PEAP)
```text
EAP ANU-Secure uXXXXXXX YourPassword
```
*Note:* The optional fourth parameter specifies the outer anonymous identity. If omitted, it defaults to the username.

#### Option B: Standard Wi-Fi / Test Hotspot (WPA2-PSK)
For home, lab, or phone hotspot testing:
```text
WIFI MyHotspot MyPassword123
```

### 3. Configure Central Server URL & API Key
Set the destination API endpoint and authorization token:
```text
SERVER http://10.28.x.x:8000/api/v1/telemetry/batch
APIKEY your_secret_api_key_here
```
*(If your server has no API key configured, `APIKEY` can be left blank).*

### 4. Enable Both Wi-Fi and Serial Egress
Set the egress mode to `BOTH` so telemetry is sent to the central server via HTTP POST while simultaneously outputting CSV over USB serial:
```text
MODE BOTH
```

### 5. Save Configuration to NVS Flash
Persist the network credentials, server URL, and mode across reboots:
```text
SAVE
```

---

## 5. Step 3: Verifying Connectivity on the Gateway

Once configured, verify connectivity using the diagnostic commands in the serial monitor:

### 1. Verify Wi-Fi and Status
```text
STATUS
```
Verify the output indicates:
```text
[STATUS] Receiver Status:
  Mode: BOTH (HTTP + Serial)
  WiFi: Connected (IP: 10.28.x.x, RSSI: -62 dBm)
  NTP:  Synchronized (UTC: 2026-10-04T08:30:15.120Z)
  Server: http://10.28.x.x:8000/api/v1/telemetry/batch
  LoRa: Frequency=915.0 MHz, SF=7, BW=125.0 kHz
```

### 2. Verify Atomic NTP Synchronization
```text
NTP
```
*Expected Output:*
```text
[NTP] Status: Synchronized
[NTP] Current UTC: 2026-10-04T08:30:15.120Z (Epoch: 1791102615)
```

### 3. Send an Immediate Synthetic Test Batch
To verify end-to-end HTTP posting without waiting for a sensor transmission:
```text
TESTPOST
```
*Expected Output:*
```text
[HTTP EGRESS] Sending synthetic test batch to http://10.28.x.x:8000/api/v1/telemetry/batch ...
[HTTP EGRESS] POST 1 samples -> HTTP 201 Created (42 ms)
```

---

## 6. Step 4: Verifying the SPRINGBANK $\rightarrow$ ROOF $\rightarrow$ Server Flow

1. Power up the **SPRINGBANK** sensor node (via battery or USB).
2. Watch the **ROOF** gateway serial console. Every 10 seconds, you should observe:
   ```text
   [LORA RX] Received batch from SPRINGBANK (10 samples, Age: 45 ms, RSSI: -72 dBm, SNR: 8.5 dB)
   [TIME] Anchoring samples: TX base age = 45 ms, NTP UTC = 2026-10-04T08:35:10.045Z
   [HTTP EGRESS] POST 10 samples -> HTTP 201 Created (38 ms)
   SPRINGBANK,2026-10-04T08:35:01.045Z,23415.20,-4120.80,48910.10,23.50,4.12,-72,0x000000
   SPRINGBANK,2026-10-04T08:35:02.045Z,23414.80,-4121.10,48911.20,23.50,4.12,-72,0x000000
   ...
   ```
3. Observe the ROOF gateway OLED display:
   * Header: `ROOF GATEWAY`
   * Line 1: `WiFi: OK (10.28.x.x)`
   * Line 2: `NTP: SYNCED`
   * Line 3: `Last: SPRINGBANK (-72dBm)`
   * Line 4: `Batches: 24 | Post: OK (201)`

---

## 7. Step 5: Testing Without Hardware (Software Mock Pipeline)

You can verify the Central Server and dashboard without any physical ESP32 boards connected using [`scripts/mock_roof_batch_sender.py`](file:///home/morgan/Gropbox/SMACT2026/remote_3_axis_magnetometer/scripts/mock_roof_batch_sender.py).

### Start the Local Central Server:
```bash
cd central_service
python3 server.py
# Server starts on http://localhost:8000
```

### Send a Single Synthetic Batch:
In a separate terminal:
```bash
python3 scripts/mock_roof_batch_sender.py --url http://localhost:8000 --once -v
```

### Run Continuous 10-Second Simulation:
```bash
python3 scripts/mock_roof_batch_sender.py --url http://localhost:8000 --batch-size 10 --interval 10.0
```

### Verify Persistence via HTTP API:
```bash
# Check registered nodes:
curl http://localhost:8000/api/v1/nodes

# Query latest 10 samples:
curl "http://localhost:8000/api/v1/data?node_id=SPRINGBANK&limit=10&format=json"

# Open the live web dashboard in a browser:
# Navigate to: http://localhost:8000
```

---

## 8. Troubleshooting

| Symptom | Probable Cause | Diagnostic Command / Fix |
| :--- | :--- | :--- |
| `WiFi: Connecting...` hangs indefinitely | Bad credentials, out of range, or 5 GHz-only SSID | Run `WIFI <ssid> <pass>` or `EAP <ssid> <user> <pass>` again. Note ESP32-S3 only supports 2.4 GHz channels 1–13. |
| `[NTP] Status: Unsynchronized` | UDP port 123 blocked by firewall or network | Check internet access. The gateway will continue functioning using relative timestamps until NTP synchronizes. |
| `[HTTP EGRESS] POST -> HTTP ERROR 401` | Server requires an API key, but gateway key is missing or wrong | Run `APIKEY <correct_key>` and `SAVE`. |
| `[HTTP EGRESS] POST -> HTTP ERROR 422` | Malformed payload | Ensure server is running latest version of `server.py` with `node_id` optional on batch telemetry points. |
| `[HTTP EGRESS] Connection Refused` | Server is down or IP address is wrong | Verify server IP via `curl http://<server_ip>:8000/health`. Update using `SERVER http://<server_ip>:8000/api/v1/telemetry/batch`. |
| LoRa packets not arriving | Mismatched frequency or missing antenna | Ensure both nodes use 915.0 MHz (`heltec_v4_sensor` and `heltec_v4_receiver`). Verify antennas are attached. |

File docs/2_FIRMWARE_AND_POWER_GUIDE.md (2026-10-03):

# 2. Firmware & Power Optimization Guide

This guide details the firmware architecture, batch transmission structures, interactive serial CLI commands, and low-power techniques implemented in both the Sensor and Receiver nodes.

---

## 1. Binary Packet Architecture (`TelemetryPacket.h`)

To maximize wireless range and minimize radio active time, all telemetry is packed into compact, unpadded binary structs:

```cpp
struct __attribute__((packed)) CompactSample {
    float x_nT; // Magnetic field X in nanoteslas
    float y_nT; // Magnetic field Y in nanoteslas
    float z_nT; // Magnetic field Z in nanoteslas
};

struct __attribute__((packed)) SensorBatchPacket {
    char          device_id[8];         // Null-terminated identifier (e.g. "NODE_3A8" or "CREEK")
    uint32_t      latest_sample_age_ms; // Age in ms of newest sample at instant of TX
    uint16_t      sample_interval_ms;   // Time between samples in ms (1000 ms = 1 Hz)
    uint8_t       sample_count;         // Number of samples in batch (up to 18)
    uint16_t      status;               // Status word
    uint16_t      vbat_mv;              // Battery voltage in mV
    int16_t       temp_c_x100;          // Temperature in deg C * 100 (0x7FFF = invalid/unmeasured)
    CompactSample samples[18];          // Dynamic catch-up buffer (up to 237 bytes)
};

struct __attribute__((packed)) GatewayAdvPacket {
    uint16_t      company_id;           // 0xFFFF (Test / Non-registered company identifier)
    uint8_t       magic[2];             // 0x4D, 0x47 ("MG" for Mag Gateway)
    uint8_t       packet_seq;           // Transmission sequence counter (0-255)
    char          node_id[8];           // Field node identifier (null-terminated)
    uint64_t      timestamp_us;         // Microsecond timestamp of newest sample
    uint16_t      sample_interval_ms;   // Sample interval in ms (1000 ms)
    uint8_t       sample_count;         // Number of samples in packet (0 to 18)
    uint16_t      status;               // Status word
    uint16_t      vbat_mv;              // Battery voltage in mV
    int16_t       temp_c_x100;          // Temperature in deg C * 100 (0x7FFF = invalid/unmeasured)
    int8_t        rssi;                 // Signal strength in dBm
    uint16_t      gw_vbat_mv;           // Gateway battery voltage in mV
    CompactSample samples[18];          // Up to 18 samples (45 to 249 bytes)
};
```
* **Payload Compliance:** Both structures fit safely inside the standard 251-byte Bluetooth 5.0 LE Extended Advertising auxiliary PDU limit.

---

## 2. Sensor Node CLI Commands

Connect to the sensor node over USB serial at **921600 baud** to access the CLI:

| Command | Arguments | Description |
| :--- | :--- | :--- |
| `HELP` / `STATUS` | None | Print system uptime, sensor status, battery voltage, and current settings |
| `ID <name>` | String | Set node identifier (e.g. `ID CREEK`) |
| `MODE <BLE\|LORA\|ESPNOW\|WIFI\|BOTH>` | Enum | Set primary wireless output protocol |
| `BATCH <1-18>` | Integer | Set batching size (e.g. `BATCH 10` sends 1 burst every 10 seconds; up to 18 for catch-up) |
| `SENSOR <RM3100\|FLC100\|MOCK>` | Enum | Select active magnetometer hardware |
| `RATE <0x90-0x98>` | Hex | Set RM3100 continuous sampling rate (`0x95` = 75 Hz) |
| `STREAM <ON\|OFF>` | None | Enable or disable live streaming |
| `SAVE` | None | Persist configuration to Flash NVS |
| `REBOOT` | None | Software reboot MCU |

---

## 3. Receiver Gateway CLI Commands

Connect to the receiver gateway at **921600 baud**:

| Command | Arguments | Description |
| :--- | :--- | :--- |
| `HELP` / `STATUS` | None | Display receiver statistics, packet counts, and active sensor table |
| `NODES` | None | Print table of all tracked remote sensor nodes, RSSI, and last heard times |
| `MODE <BLE\|SERIAL\|WIFI\|BOTH>` | Enum | Set egress forwarding target (`BLE` activates connectionless 1M Extended Adv, Wi-Fi radio OFF) |
| `DEBUG [ON\|OFF]` | None / Enum | Toggle BLE rendezvous and discovery debug logging |
| `WIFI <ssid> <pass>` | Strings | Set router credentials for Wi-Fi egress mode |
| `TARGET <ip> [port]` | String, Int | Set target Central Server IP & UDP port for Wi-Fi egress |
| `CHANNEL <1-13>` | Integer | Set ESP-NOW Wi-Fi channel |
| `SAVE` | None | Save configuration to Flash NVS |
| `REBOOT` | None | Software reboot MCU |

---

## 4. Power Optimization & Sleep Architecture

### A. Sensor Node Optimizations:
1. **Low-Duty-Cycle Coded PHY Bursting:** The BLE radio is powered ON for only **300 ms** every 10 seconds (`BATCH 10`), remaining **100% OFF for 9.7 seconds** (>97% radio sleep duty cycle).
2. **Dynamic 18-Sample Catch-Up:** If the gateway is temporarily offline or out of range, un-ACKed samples accumulate in a circular ring buffer (up to 600 samples / 10 minutes) and burst up to 18 samples per transmission until caught up.
3. **Hardware `AUX_SCAN_REQ` ACKs:** Uses hardware scan requests to clear the ring buffer tail with zero transmission overhead.
4. **LoRa SX1262 Deep Sleep:** In `MODE LORA`, the SX1262 is put into deep sleep ($<1\,\mu\text{A}$) using `loraStream.sleep()`.
5. **Synchronized Battery Divider:** The resistive divider for $V_{bat}$ sensing is sampled strictly during the 10s burst wakeup, eliminating parasitic divider current between bursts.
6. **OLED Auto-Sleep:** Powers down after 30 seconds of inactivity (~20 mA savings) and re-awakens on **GPIO 0 (USER button)** press.

### B. Receiver Gateway Optimizations:
1. **Slotted Rendezvous Sleep Protocol:**
   - The receiver tracks remote sensor burst cadences via EWMA smoothing ($(3 \times \text{period} + dt) / 4$) within a bounded acceptance window ($7,500\text{ ms} - 12,500\text{ ms}$).
   - **Backlog Invariance Rule**: `nominalPeriod` is fixed at $10.0\text{ s}$ and NEVER computed from `sample_count`. When a sensor drains backlog, `sample_count` reaches 18, but transmission remains strictly on the 10.0s grid.
   - During the ~9.4-second gap between bursts, NimBLE is cleanly deinitialized and the hardware Bluetooth controller is disabled (`NimBLEDevice::deinit(false)` + `esp_bt_controller_disable()`), achieving a **~97% radio sleep duty cycle** and dropping current to **10 mA** base at 40 MHz CPU (bench-verified).
   - The receiver wakes up with a **350 ms lead time** prior to the predicted burst. This 350 ms margin absorbs up to ±3% uncalibrated crystal drift on cold boot before EWMA converges, and easily absorbs the ~10–15 ms NimBLE initialization overhead.
   - Upon receiving the batch, the receiver shuts off its radio immediately (~5 ms after RX), resulting in actual radio on-times of only ~50–100 ms.
   - **Immediate Discovery Lock**: In `STATE_DISCOVERY`, the scheduler immediately exits upon the first valid batch reception, eliminating 12-second 75 mA discovery freezes.
   - **Dedicated Coded PHY Scanning**: Active scan is locked to Coded PHY (`pScan->setPhy(NimBLEScan::Phy::SCAN_CODED)`) to guarantee 100% duty cycle reception and instant `AUX_SCAN_REQ` hardware ACKs.
2. **Connectionless 1Mbps Extended Advertising Egress:**
   - Transmits telemetry bursts connectionlessly via BLE 5.0 1M Extended Advertising auxiliary PDUs (`Company ID 0xFFFF`, magic `b"MG"`).
   - Eliminates connection handshakes, GATT pairing delays, supervision timeouts, and slave latency requirements.
3. **Wi-Fi Radio Power-Down:** In `MODE BLE`, the Wi-Fi subsystem is shut down (`WiFi.mode(WIFI_OFF)`), saving **$\sim 80\text{ mA}$**.
4. **Sleep State Independence from USB CDC:**
   - On the `SUPERMINI_GATEWAY` receiver profile, USB-CDC is disabled on boot (`ARDUINO_USB_MODE=0`, `ARDUINO_USB_CDC_ON_BOOT=0`), eliminating USB PHY power draw (~15 mA saved).
   - Real-time diagnostics (sync acquired, window timeout, lost sync discovery) are broadcast via BLE Extended Advertising diagnostic packets and parsed by `scripts/ble_monitor.py`.

---

## 5. Ongoing Profiling & Power Investigation Tasks

- **Sensor Node Sleep Current Profiling ("CREEK")**: The current sensor build for `CREEK` still draws $\sim 30\text{ mA}$ between broadcasting batches of samples (in mock data mode, with no physical sensor attached). In principle, dynamic frequency scaling (DFS) and light sleep should drop this baseline to $\sim 10\text{ mA}$. All that is required during this inter-burst period is SPI polling of the ADC (for FLC100 fluxgate sensors) or DRDY interrupt waiting. Further investigation is needed to verify which peripheral clocks or FreeRTOS timers are preventing deeper idle states.
- **Heltec V4 + LoRa Power Profiling ("SPRINGBANK")**: Conduct a parallel power profiling and sleep budget analysis for the Heltec V4 ESP32-S3 + SX1262 LoRa firmware, verifying SX1262 deep sleep current ($<1\,\mu\text{A}$) and ESP32-S3 light sleep current between scheduled LoRa transmission bursts.

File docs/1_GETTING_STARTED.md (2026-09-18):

# 1. Getting Started Guide

This guide covers initial hardware setup, wiring, toolchain configuration, firmware building, and provisioning for the Remote 3-Axis Magnetometer project.

---

## 1. System Overview

The system consists of three primary layers:

```
+---------------------------+       Wireless Burst (10s)       +---------------------------+       1 Mbps BLE / USB        +---------------------------+
|    Remote Sensor Node     | -------------------------------> |  Outside Receiver Gateway | ----------------------------> |  Host Computer / Phone    |
| (ESP32-C3 / XIAO ESP32-C6 |    BLE Coded PHY (S=8) or        | (ESP32-C3 / XIAO ESP32-C6 |    (nRF Connect / Bleak /     | (Web Dashboard / Grafana/ |
|  / Heltec V4 + Mag Sensor)|    SX1262 LoRa (915 MHz)         |  / Heltec V4, Wi-Fi OFF)   |     Serial / UDP Central)     |  Desktop PySide6 HDF5 App)|
+---------------------------+                                  +---------------------------+                               +---------------------------+
```

1. **Remote Sensor Node**: Gathers magnetic field vectors ($B_x, B_y, B_z$), packs 10 samples into a binary batch (with centi-degree temperature and battery voltage), and transmits over Coded PHY S=8 or LoRa before sleeping.
2. **Receiver Gateway**: Receives the bursts over long-range RF (BLE Coded PHY or LoRa) with Wi-Fi powered OFF to save power, and relays the telemetry over standard 1 Mbps BLE Extended Advertising, USB Serial, or Wi-Fi.
3. **Host Ingest**: Any phone (via **nRF Connect**) or laptop (via `scripts/ble_monitor.py`) displays real-time vectors and logs to CSV or Central Server.

---

## 2. Hardware Pinouts & Wiring

### A. ESP32-C3 SuperMini (Sensor & Receiver)
* **SPI Bus (RM3100 / ADS131E08 ADC):**
  * `SCK`: GPIO 6
  * `MOSI`: GPIO 7
  * `MISO`: GPIO 2
  * `DRDY`: GPIO 3
  * `CS`: GPIO 10
* **Status LED:** GPIO 8 (Active-LOW, Blue LED)
* **Battery Sensing:** GPIO 4 (ADC1_CH4, 2.0× resistive divider)

### B. Seeed Studio XIAO ESP32-C6 (Sensor & Receiver)
* **SPI Bus (RM3100 / ADS131E08 ADC):**
  * `SCK`: GPIO 1
  * `MOSI`: GPIO 2
  * `MISO`: GPIO 19
  * `DRDY`: GPIO 20
  * `CS`: GPIO 23
* **Status LED:** GPIO 15 (Active-LOW, Yellow LED)
* **Battery Sensing:** GPIO 0 (ADC1_CH0, 2.0× resistive divider)

### C. Heltec WiFi LoRa 32 V3 / V4 (ESP32-S3 + SX1262 LoRa + OLED)
* **SPI Bus (RM3100 / ADS131E08 ADC):**
  * `SCK`: GPIO 41
  * `MOSI`: GPIO 42
  * `MISO`: GPIO 40
  * `DRDY`: GPIO 38
  * `CS`: GPIO 39
* **Integrated OLED (SSD1306):** SDA=17, SCL=18, RST=21, Vext=36
* **Integrated SX1262 LoRa:** CS=8, DIO1=14, RST=12, BUSY=13, SCK=9, MISO=11, MOSI=10
* **Battery Sensing:** ADC=GPIO 1, Divider Ctrl=GPIO 37 (4.90× divider + P-MOSFET gate)
* **User Wake Button:** GPIO 0 (`INPUT_PULLUP`)

---

## 3. Toolchain & Dependencies

* **PlatformIO CLI / Core:**
  ```bash
  pip install platformio
  ```
* **Python Host Tools:**
  ```bash
  pip install -r central_service/requirements.txt
  pip install bleak
  ```

---

## 4. PlatformIO Environments

The project defines modular PlatformIO targets in [`platformio.ini`](file:///home/morgan/Gropbox/SMACT2026/remote_3_axis_magnetometer/platformio.ini):

| Target Environment | Target Hardware | Role | Build Filter |
| :--- | :--- | :--- | :--- |
| `esp32-c3-devkitm-1` | ESP32-C3 SuperMini | Sensor Node | `+<*> -<receiver/*>` |
| `esp32c3_receiver` | ESP32-C3 SuperMini | Receiver Gateway | `+<receiver/*>` |
| `esp32-c6-devkitc-1` | Seeed XIAO ESP32-C6 | Sensor Node | `+<*> -<receiver/*>` |
| `esp32c6_receiver` | Seeed XIAO ESP32-C6 | Receiver Gateway | `+<receiver/*>` |
| `heltec_v4_sensor` | Heltec V4 (ESP32-S3) | Sensor Node | `+<*> -<receiver/*>` (`-D HELTEC_V4`) |
| `heltec_v4_receiver` | Heltec V4 (ESP32-S3) | Receiver Gateway | `+<receiver/*>` (`-D HELTEC_V4`) |

### Building and Flashing:
```bash
# Flash ESP32-C3 as Sensor Node (e.g. on /dev/ttyACM0)
pio run -e esp32-c3-devkitm-1 -t upload --upload-port /dev/ttyACM0

# Flash ESP32-C3 as Receiver Gateway (e.g. on /dev/ttyACM1)
pio run -e esp32c3_receiver -t upload --upload-port /dev/ttyACM1

# Flash Seeed XIAO ESP32-C6 as Sensor Node
pio run -e esp32-c6-devkitc-1 -t upload --upload-port /dev/ttyACM0
```

---

## 5. Node Provisioning

Use the interactive provisioning wizard to configure node settings:

```bash
# Interactive configuration wizard
python3 scripts/provision_node.py -i

# Or set via CLI arguments
python3 scripts/provision_node.py --port /dev/ttyACM1 --id MAG_NODE_01 --mode BLE --batch 10

# Provision Receiver Gateway
python3 scripts/provision_receiver.py --port /dev/ttyACM0 --mode BLE
```

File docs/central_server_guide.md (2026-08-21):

# Central Server & Web GUI Guide (`docs/central_server_guide.md`)

This guide covers operating the **Central Data Server** (`central_service/server.py`), the **Edge Gateway Relay** (`central_service/gateway.py`), accessing the Web GUI, and exporting telemetry data.

---

## 1. Quick Setup & Running the Services

### Automated Installation (Raspberry Pi 4 / Laptop)
Run the automated installer script to set up Python virtual environments, configure `.env`, install auto-starting systemd services, and apply hardware optimizations:

```bash
cd central_service
sudo ./install.sh
```

### Managing the Server (`./manage.sh`)
```bash
./manage.sh status                  # Display status, database size, memory, and telemetry counts
./manage.sh logs                    # Live stream logs
./manage.sh restart                 # Restart services
./manage.sh backup                  # Safe online SQLite snapshot into backups/
./manage.sh nodes                   # List all registered sensor nodes and GPS coordinates
./manage.sh node delete TEST        # Delete unwanted/test node (add --purge to delete telemetry)
./manage.sh node prune --days 30    # Prune inactive nodes not seen in >30 days
```

### Manual Execution
```bash
cd central_service
python server.py
# In another terminal / background:
python gateway.py
```
- Server URL: `http://localhost:8000`
- Interactive OpenAPI Docs: `http://localhost:8000/docs`

### Residential NAT & Remote Access (`./remote_access.sh`)
If deploying behind a residential home router with dynamic IP or Carrier-Grade NAT (CGNAT):
```bash
./remote_access.sh
```
See the dedicated [**Residential NAT & Remote Access Guide**](NAT_AND_REMOTE_ACCESS.md) and [**Server Hardware Setup Guide**](SERVER_SETUP_GUIDE.md).

---

## 2. Web GUI Features

Access `http://localhost:8000` in any modern web browser:

1. **Active Node Cards**: Real-time signal strength (RSSI), battery voltage ($V_{bat}$), sample rate (Hz), and total packet count per node.
2. **Time-Series Plots**: Live 3-axis magnetic field graph ($B_x, B_y, B_z$ in nT) powered by WebSockets.
3. **Power Spectral Density (PSD)**: Real-time FFT spectrum display with noise floor analysis ($\text{pT}/\sqrt{\text{Hz}}$).
4. **Data Exporter**: Export raw or downsampled telemetry directly from the web browser.

---

## 3. REST API v1 Reference

| Method | Endpoint | Description |
| :--- | :--- | :--- |
| `GET` | `/health` | Server health check & active database status |
| `POST` | `/api/v1/telemetry/batch` | Ingest batched array of sensor telemetry items |
| `GET` | `/api/v1/nodes` | List active remote sensor nodes with RSSI & battery metrics |
| `GET` | `/api/v1/telemetry/recent` | Query recent telemetry points with limit and downsampling |
| `GET` | `/api/v1/data/export` | Download exported data in CSV, Parquet, NumPy, or JSON format |
| `WS` | `/ws/telemetry` | WebSocket stream for live time-series plotting |

---

## 4. Supported Export Formats

Telemetry can be exported via the Web GUI or API using the `/api/v1/data/export` endpoint:

1. **CSV (`format=csv`)**: Human-readable 6-column tabular data stream.
2. **Apache Parquet (`format=parquet`)**: High-performance, columnar compressed binary format (Snappy/ZSTD compression). Ideal for Pandas/Polars data science pipelines.
3. **NumPy Array (`format=npz`)**: Compressed `.npz` archive containing `timestamps`, `x_nT`, `y_nT`, and `z_nT` arrays.
4. **JSON (`format=json`)**: Structured JSON list of telemetry objects.

### Example Export Python Script
```python
import requests

url = "http://localhost:8000/api/v1/data/export?format=parquet&limit=10000"
response = requests.get(url)

with open("telemetry_export.parquet", "wb") as f:
    f.write(response.content)

print("Saved telemetry_export.parquet successfully.")
```

---

## 5. Station Metadata & GPS Location Management (`scripts/update_node.py`)

To assign or update station names, GPS coordinates, elevation, and site notes for deployed nodes:

```bash
# 1. Update station location and site notes
python3 scripts/update_node.py --node NODE_3A8 --name "North Ridge" --lat -33.8568 --lon 151.2153 --elev 42.5 --notes "Borehole #3 site"

# 2. List all registered nodes and their coordinates
python3 scripts/update_node.py --list

# 3. Interactive prompt wizard (prompts for fields interactively)
python3 scripts/update_node.py -i

# 4. Delete an unwanted test node (add --purge to also delete historical telemetry)
python3 scripts/update_node.py --delete TEST_NODE --purge

# 5. Prune all nodes inactive for more than 30 days
python3 scripts/update_node.py --prune-inactive 30 --purge
```

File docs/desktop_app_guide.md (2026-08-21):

# Desktop Application Guide (`docs/desktop_app_guide.md`)

This guide covers running and using the **PySide6 Desktop Application** (`desktop_app/main.py`) for high-speed local serial visualization, spectral analysis, and HDF5 logging.

---

## 1. Running the Application

Ensure your Conda environment is activated (`conda activate rm3100`):

```bash
python desktop_app/main.py
```

---

## 2. Key Features & Interface Overview

1. **High-Speed Real-Time Plotting**:
   - Time-series plotting of 3-axis magnetic field ($B_x, B_y, B_z$) in calibrated Nanotesla ($\text{nT}$) and total vector magnitude ($|\mathbf{B}|$).
   - Built on `pyqtgraph` for high frame rates at up to 1000 Hz sampling (e.g. 100 Hz FLC100 or 75 Hz RM3100).
   - Automatic unit scaling in Nanotesla ($\text{nT}$).

2. **Welch Power Spectral Density (PSD)**:
   - Compute real-time FFT frequency spectrum ($\text{nT}/\sqrt{\text{Hz}}$) with configurable FFT window sizes (64 to 1024 points).
   - Real-time noise floor tracking for geomagnetic anomaly and noise detection.

3. **HDF5 High-Performance Data Logger**:
   - Stream raw data directly to compressed HDF5 files (`.h5`) with Gzip chunk compression.
   - Preserves high-precision 64-bit microsecond timestamps (`timestamp_us`) and 32-bit float magnetic vector columns.

4. **Dynamic Hardware NVS Provisioning**:
   - Direct support for **PNI RM3100** (digital cycle counts 50–400) and **FLC100 + ADS131E08** (24-bit ADC software decimation 1x–100x and PGA gains 1x–8x).
   - Configure active device ID, downsampling, and output modes directly over USB serial.

> [!NOTE]
> **Connecting over USB Serial**: Ensure the target node is configured in `MODE SERIAL` or `MODE BOTH` (`MODE SERIAL; STREAM ON; SAVE`). If the node is in `MODE WIFI` or `MODE BLE`, it will not stream over USB.

---

## 3. Data Export & Post-Processing

HDF5 files saved by the Desktop Application can be loaded into Python for analysis:

```python
import h5py
import numpy as np

with h5py.File("magnetometer_run_001.h5", "r") as f:
    timestamps = f["timestamps"][:]
    bx = f["x_nT"][:]
    by = f["y_nT"][:]
    bz = f["z_nT"][:]

print(f"Loaded {len(timestamps)} samples. Bx mean: {np.mean(bx):.2f} nT")
```

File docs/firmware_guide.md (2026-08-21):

# Firmware Flashing & Hardware Guide (`docs/firmware_guide.md`)

This guide covers building, flashing, configuring, and operating both the **Field Sensor Node Firmware** (`src/main.cpp`) and the **Multi-Protocol Receiver Gateway Firmware** (`src/receiver/`).

---

## 1. PlatformIO Target Environments

All target builds are configured in [`platformio.ini`](../platformio.ini):

### Field Sensor Node Targets
```bash
# Heltec V4 Sensor Node (ESP32-S3 + SX1262 LoRa)
pio run -e heltec_v4_sensor -t upload --upload-port /dev/ttyACM0

# ESP32-C6 Sensor Node (Wi-Fi 6 / 802.15.4)
pio run -e esp32-c6-devkitc-1 -t upload --upload-port /dev/ttyACM0

# ESP32-C3 Sensor Node PCB
pio run -e esp32-c3-devkitm-1 -t upload --upload-port /dev/ttyACM0
```

### Multi-Protocol Receiver Gateway Targets
```bash
# Heltec V4 Receiver Gateway (ESP32-S3 + SX1262 LoRa)
pio run -e heltec_v4_receiver -t upload --upload-port /dev/ttyACM1

# ESP32-C6 Receiver Gateway (Wi-Fi 6 / BLE Coded PHY / ESP-NOW)
pio run -e esp32c6_receiver -t upload --upload-port /dev/ttyACM1

# ESP32-C3 Receiver Gateway PCB
pio run -e esp32c3_receiver -t upload --upload-port /dev/ttyACM1
```

---

## 2. Pinout Reference Table

| Target Hardware Board | PlatformIO Env (`Sensor` / `Receiver`) | Sensor SCK | Sensor MOSI | Sensor MISO | Sensor CS | Sensor DRDY | LoRa CS / DIO1 / RST / BUSY | Vext Rail |
| :--- | :--- | :--- | :--- | :--- | :--- | :--- | :--- | :--- |
| **ESP32-C3 RISC-V PCB** | `esp32-c3-devkitm-1` / `esp32c3_receiver` | GPIO 6 | GPIO 7 | GPIO 2 | GPIO 10 | GPIO 3 | GPIO 5 / 4 / 14 / 15 | N/A |
| **ESP32-C6 Wi-Fi 6 PCB** | `esp32-c6-devkitc-1` / `esp32c6_receiver` | GPIO 6 | GPIO 7 | GPIO 2 | GPIO 10 | GPIO 3 | GPIO 5 / 4 / 14 / 15 | N/A |
| **Heltec V4 (ESP32-S3 + SX1262)** | `heltec_v4_sensor` / `heltec_v4_receiver` | GPIO 41 | GPIO 42 | GPIO 40 | GPIO 39 | GPIO 38 | GPIO 8 / 14 / 12 / 13 | GPIO 36 |
| **Legacy ESP32 Dev (WROOM)** | `esp32dev` / `esp32dev_receiver` [Deprecated] | GPIO 18 | GPIO 23 | GPIO 19 | GPIO 5 | GPIO 4 | GPIO 5 / 4 / 14 / 15 | N/A |

---

## 3. Interactive Serial CLI Reference

Connect via USB serial at **921,600 baud**:

```bash
pio device monitor -b 921600
```

### Receiver Gateway CLI Commands
| Command | Description | Example |
| :--- | :--- | :--- |
| `HELP` / `STATUS` | Query receiver status, protocol packet counts, and network info | `STATUS` |
| `NODES` | Print real-time table of active remote sensor nodes with RSSI & Vbat | `NODES` |
| `MODE <SERIAL\|WIFI\|BOTH>` | Select egress relay destination (USB Serial, WiFi Network, or Dual Egress) | `MODE BOTH` |
| `WIFI <ssid> <pass>` | Save egress router credentials and connect to WiFi network | `WIFI MySSID secret123` |
| `TARGET <ip> [port]` | Configure target Central Server IP and port for WiFi forwarding | `TARGET 192.168.1.50 9876` |
| `CHANNEL <1-13>` | Set ESP-NOW WiFi radio channel | `CHANNEL 1` |
| `SAVE` | Persist current configuration to Flash NVS memory | `SAVE` |
| `REBOOT` | Restart receiver MCU | `REBOOT` |

### Sensor Node CLI Commands
| Command | Description | Example |
| :--- | :--- | :--- |
| `HELP` / `STATUS` | Query Device ID, sensor model, rate code, and hardware status | `STATUS` |
| `STREAM ON` / `OFF` | Enable / disable continuous telemetry stream | `STREAM ON` |
| `ID <name>` | Configure custom Device ID / Node name (saves to NVS Flash) | `ID NODE_ALPHA` |
| `SENSOR <RM3100\|FLC100\|MOCK>` | Set active sensor driver (`FLC100` = 24-bit ADS131E08 ADC, `MOCK` = Range testing with synthetic telemetry and status `0x80MOCK`) | `SENSOR FLC100` |
| `DOWNSAMPLE <int>` | Set MCU software decimation ratio (`10` = 100 Hz from 1 kSPS ADC, `1000` = 1 Hz; saved to NVS) | `DOWNSAMPLE 10` |
| `RATE <hex>` | Set rate code (`0x95` = 75 Hz, `0x94` = 150 Hz, `0x93` = 300 Hz, `0x92` = 600 Hz) | `RATE 95` |
| `CYCLE <int>` | Set RM3100 oscillation cycle count | `CYCLE 200` |
| `BATCH <1-10>` | Set samples per burst for BLE & LoRa (`1` = real-time 1 Hz, `10` = max low-power mode; saved to NVS) | `BATCH 10` |
| `MODE <SERIAL\|WIFI\|BLE\|LORA\|BOTH>` | Route stream to USB Serial, WiFi UDP, BLE Coded PHY, Sub-GHz LoRa, or Dual Egress | `MODE SERIAL` |

---

## 4. Standalone Field Access Point (SoftAP) Architecture

The system supports **routerless field operation** using the Gateway Receiver's built-in Access Point:

```
+------------------------------------+        Direct Wi-Fi UDP        +-----------------------------------+
|     Remote Field Sensor Node       |  ----------------------------> |      Gateway Receiver Node        |
|  SSID: MAG_GATEWAY_XXXX            |      (Port 9876 @ 1 Hz)        |  SoftAP IP:  192.168.4.1          |
|  Assigned IP: 192.168.4.2           |                                |  SSID:       MAG_GATEWAY_XXXX    |
|  Target IP:   192.168.4.1          |                                |  Mode:       WIFI_AP_STA         |
+------------------------------------+                                +-----------------------------------+
                                                                                        |
                                                                             USB Serial | (or External STA)
                                                                                        v
                                                                      +-----------------------------------+
                                                                      |  Edge Relay / Central Data Server |
                                                                      +-----------------------------------+
```

- **Routerless Field SoftAP**: On boot, the Gateway Receiver launches a 2.4GHz WPA2 Access Point (`MAG_GATEWAY_XXXX`, Password: `magnetometer123`) on `192.168.4.1` (Channel 1). Remote sensor nodes connect directly to the Gateway without requiring an external 3rd-party Wi-Fi router or cellular hotspot.
- **Hybrid AP+STA Mode**: The Gateway Receiver runs in dual `WIFI_AP_STA` mode. It serves as the local Access Point for field sensors while maintaining an optional STA link to an external router (if configured via `WIFI "SSID" Pass`) for central server egress.
- **Standalone CLI Control**:
  - `WIFI CLEAR` / `WIFI OFF` (on Gateway): Clears external router credentials and locks the Gateway into standalone field SoftAP mode.
  - `WIFI STATUS` (on Gateway): Prints active SoftAP SSID (`MAG_GATEWAY_XXXX`), SoftAP IP (`192.168.4.1`), and external STA connection status.

---

## 5. Supported Radio Protocols

1. **Sub-GHz LoRa (Semtech SX1262)**:
   - Range: 2–10+ km (sub-GHz 868 / 915 MHz).
   - Ideal for long-range field sensor monitoring.
2. **ESP-NOW**:
   - Fast connectionless MAC-layer protocol (transmit time <1 ms).
   - Minimal power consumption for battery nodes.
3. **Bluetooth 5.0 LE / Coded PHY**:
   - Extended Advertising (Coded PHY S=8, +12 dB sensitivity gain, max +15 dBm TX power) with configurable batch burst transmission (`BATCH 1..10`).
4. **WiFi UDP (SoftAP / Router STA)**:
   - Direct UDP packet streaming on port 9876 over local Field SoftAP (`192.168.4.1`) or infrastructure Wi-Fi networks.

---

## 6. Power Management & Low-Power Batch Telemetry Architecture (Primary Mode)

Going forward, the **Low-Power LE Coded PHY Batch Mode with Hardware ACKs** serves as the primary field operational protocol. It is engineered to maximize battery life while guaranteeing maximum RF range and 100% data delivery integrity:

### 1. Configurable Coded PHY Batch Bursting (`BATCH 1..10`)
* **Motivation**: Continuous 1 Hz advertising keeps the BLE radio modem powered continuously (~40–80 mA), limiting battery life to ~20 hours.
* **Mechanism**: High-frequency sensor samples (75 Hz) are downsampled to 1 Hz into a RAM ring buffer. The radio modem remains **100% powered off** between batch bursts.
* **Configurable Batching (`BATCH <1-10>`)**:
  * Set via CLI (`BATCH 1` to `BATCH 10`); default is `10` samples/burst (10-second sleep interval).
  * At burst time, the BLE radio turns on for ~200 ms and broadcasts a **139-byte Coded PHY Extended Advertising PDU** (`SensorBatchPacket`) containing up to 10 compact 3-axis samples at **+15 dBm Max Power**.
* **RF Power Savings**: Reduces RF transmitter active duty cycle from ~100% to **< 0.5%**, extending battery life to **35–45 days** on a 1000 mAh LiPo.

### 2. Hardware `AUX_SCAN_REQ` ACKs & 10-Minute Disconnect Ring Buffer
* **Hardware Confirmation**: Uses native Bluetooth 5.0 `AUX_SCAN_REQ` hardware scan request frames sent automatically by the gateway upon demodulating an extended advertising payload (`onScanRequest` callback). Zero extra RF power cost.
* **10-Minute Disconnect Storage**: The sensor node maintains a 600-sample circular ring buffer (~7.2 KB SRAM) for up to **10 minutes of offline data storage**.
* **Automatic Catch-up Flushing**: If the gateway goes out of range, the sensor node retains unacknowledged samples safely in memory. Once the gateway is back in range, the sensor receives hardware ACKs and rapidly flushes the backlog in consecutive Coded PHY bursts until zero backlog remains.

### 3. Dynamic Frequency Scaling (DFS) vs. Automatic Light Sleep Rationale
* **Selected Mode**: **Dynamic Frequency Scaling (DFS)** enabled (`min_freq = 20MHz`, `max_freq = 160MHz`, `light_sleep_enable = false`).
* **Why Light Sleep (`light_sleep_enable = true`) was disabled**:
  * Enabling Light Sleep powers down the ESP32's Main 80 MHz APB (Advanced Peripheral Bus) Clock and PLL crystal oscillator during idle states.
  * Re-locking the PLL and restoring APB bus clocks upon a sensor `DRDY` (Data Ready) interrupt incurs **1.5 ms to 3.0 ms of hardware wake-up latency**.
  * At 75 Hz sampling (13.3 ms per window), this latency accounts for up to 25% of the frame interval, causing severe interrupt response jitter and **missed/corrupted sensor readings**.
* **DFS Performance**: By keeping the APB clock powered ON (`light_sleep_enable = false`), DRDY interrupt response time is **sub-microsecond (< 1 µs)** with **0% sample loss**, while CPU power is automatically throttled to 20 MHz during idle gaps (~3.5 mA system current).

### 4. Low-Power Receiver Gateway Optimizations
* **80 MHz CPU Scaling**: Receiver CPU frequency reduced from 240 MHz to **80 MHz** (`setCpuFrequencyMhz(80)`), saving ~28 mA.
* **30-Second OLED Auto-Sleep**: Display controller sleeps after 30s of inactivity (~20 mA savings); wakes instantly via the physical **PRG / USER button (GPIO 0)** or Serial CLI input.
* **Smart Wi-Fi Off**: Automatically powers off the Wi-Fi radio when operating in USB Serial Egress mode (`MODE SERIAL`), saving ~80 mA.

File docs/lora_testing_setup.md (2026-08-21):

# Heltec V4 SX1262 Sub-GHz LoRa Testing & Setup Guide

This document provides step-by-step instructions for flashing, provisioning, and testing **Sub-GHz LoRa (SX1262)** telemetry transmission between two **Heltec WiFi LoRa 32 V4 (ESP32-S3)** target boards.

---

## Hardware Pinout Reference (Heltec V4 Board)

| Signal | ESP32-S3 GPIO | Function |
| :--- | :--- | :--- |
| **SX1262 CS** | **GPIO 8** | LoRa SPI Chip Select |
| **SX1262 DIO1** | **GPIO 14** | LoRa Interrupt / RX Done |
| **SX1262 Reset** | **GPIO 12** | Hardware Reset Line |
| **SX1262 Busy** | **GPIO 13** | Hardware Status / Busy Line |
| **SX1262 SCK** | **GPIO 9** | SPI Clock |
| **SX1262 MOSI** | **GPIO 10** | SPI Master Out Slave In |
| **SX1262 MISO** | **GPIO 11** | SPI Master In Slave Out |
| **Vext Power Rail** | **GPIO 36** | Active LOW Power Rail Control (Drives OLED & LoRa power) |

---

## LoRa RF Frequency Configuration (AU915 Band)

The driver is pre-configured to operate under **Australian RF Spectrum Regulations (AU915 Band)**:

* **Frequency**: `915.0 MHz` (AU915 Band 915.0–928.0 MHz)
* **Bandwidth**: `125.0 kHz` (Optimized for maximum sensitivity ~ -123 dBm)
* **Spreading Factor**: `SF7` (Fast time-on-air and low latency)
* **Coding Rate**: `4/5`
* **Output Power**: `+22 dBm` (Maximum SX1262 TX power output with DIO2 RF switch enabled)
* **True Signal Power Calculation**: Below the thermal noise floor (-103 dBm), true RSSI is calculated as `RSSI + SNR` when $\text{SNR} < 0\text{ dB}$.

---

## Method 1: Automated Flashing & Over-The-Air Testing (Recommended)

Run the single-command automated test tool [`scripts/setup_lora_test.py`](file:///home/morgan/Gropbox/SMACT2026/remote_3_axis_magnetometer/scripts/setup_lora_test.py):

```bash
# 1. Automated Flash, Provision (10-sample batch burst), and Live Telemetry Test
python3 scripts/setup_lora_test.py --sensor-port /dev/ttyACM1 --rcvr-port /dev/ttyACM0 --batch 10

# 2. Skip Flashing (Run Provisioning & Live Test Only)
python3 scripts/setup_lora_test.py --sensor-port /dev/ttyACM1 --rcvr-port /dev/ttyACM0 --batch 10 --skip-flash
```

---

## Method 2: Manual Flashing & CLI Provisioning

### Step 1: Flash Firmware via PlatformIO

```bash
# 1. Flash Receiver Firmware (Heltec V4 connected to /dev/ttyACM0)
pio run -e heltec_v4_receiver -t upload --upload-port /dev/ttyACM0

# 2. Flash Sensor Firmware (Heltec V4 connected to /dev/ttyACM1)
pio run -e heltec_v4_sensor -t upload --upload-port /dev/ttyACM1
```

---

### Step 2: Provision the Field Sensor Node (`/dev/ttyACM1`)

Open a terminal or serial monitor (`pio device monitor -p /dev/ttyACM1 -b 921600`) and enter the following CLI commands:

```text
SENSOR MOCK
ID NODE_LORA_01
BATCH 10
MODE LORA
STREAM ON
SAVE
```

---

### Step 3: Provision the Gateway Receiver Node (`/dev/ttyACM0`)

Open a terminal or serial monitor (`pio device monitor -p /dev/ttyACM0 -b 921600`) and enter:

```text
MODE SERIAL
SAVE
```

---

## Live Monitoring Output

When telemetry packets arrive over the air, the Gateway Receiver (`/dev/ttyACM0`) outputs standard 6-column CSV telemetry lines with RSSI:

```text
NODE_LORA_01,1442000,21623.00,-3162.00,43222.00,004D4F,0.0,3.30,-48
NODE_LORA_01,1443000,21625.00,-3161.00,43224.00,004D4F,0.0,3.30,-48
```

---

## Troubleshooting

1. **`[LORA ERROR] Failed to initialize SX1262 module (code: -2)`**:
   - Ensure the Heltec Vext power rail is turned ON. In firmware setup, `initBoardPower()` pulls GPIO 36 `LOW`.
2. **No Packets Received Over-The-Air**:
   - Ensure antennas are securely attached to both Heltec V4 boards. Running LoRa transmitters without antennas can damage the RF power amplifier.
   - Verify both nodes are configured to the same frequency (`915.0 MHz`) and bandwidth (`500.0 kHz`).

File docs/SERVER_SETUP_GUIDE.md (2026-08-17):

# Central Server Deployment & Hardware Setup Guide

This guide provides instructions for deploying the **Magnetometer Central Data Server & Gateway** on low-cost residential hardware, specifically:
- **Raspberry Pi 4** (Raspberry Pi OS / Debian 64-bit / 32-bit)
- **Old Laptop / Mini-PC** (Ubuntu, Debian, Linux Mint, WSL2, or macOS)

---

## 1. Quick Start: One-Command Automated Setup

On your target machine (Raspberry Pi or Laptop), navigate to the `central_service` directory and run the installer:

```bash
cd central_service
sudo ./install.sh
```

### What `install.sh` Does Automatically:
1. **Installs System Packages**: Installs `python3`, `python3-venv`, `python3-pip`, `sqlite3`, `curl`, and network diagnostics.
2. **Creates Python Environment**: Creates a dedicated `.venv` and installs required packages (`fastapi`, `uvicorn`, `pydantic`, `numpy`, `pandas`, `requests`, `pyarrow`, `pyserial`).
3. **Generates `.env`**: Sets up default configuration for server port (8000), UDP port (9876), database path, and optional `API_KEY`.
4. **Installs Systemd Services**:
   - `magnetometer-server.service` (central server & web GUI)
   - `magnetometer-gateway.service` (UDP / Serial sensor stream forwarder)
   - Configures automatic restart on crashes and auto-start on boot.
5. **Applies Hardware Optimizations**:
   - **Laptops**: Disables sleep on lid close and disables Wi-Fi power-saving sleep.
   - **Raspberry Pi**: Ensures SQLite WAL mode is active for safe, low-wear SD card operation.
6. **Displays Access URLs**: Prints local IP addresses and dashboard links (`http://192.168.x.x:8000`).

---

## 2. Daily Operations & Management (`manage.sh`)

Use `./manage.sh` to control, monitor, and maintain the server without remembering systemd commands:

```bash
# Check server health, memory, database size, total records, and active nodes
./manage.sh status

# View live colorized logs from server and gateway
./manage.sh logs

# Restart or stop services
./manage.sh restart
./manage.sh stop
./manage.sh start

# Create an instant, safe SQLite online backup (stored in backups/)
./manage.sh backup

# Quick CLI telemetry export to CSV, Parquet, or NumPy NPZ
./manage.sh export csv
./manage.sh export parquet

# Send a synthetic self-test sample to verify the ingestion pipeline
./manage.sh test
```

---

## 3. Hardware Target 1: Old Laptop

An old laptop makes a server because it has a **built-in uninterruptible power supply (battery)**, screen/keyboard for recovery, and low idle power consumption (10–15 W).

### Key Laptop Optimizations:

#### A. Keep Running When Lid is Closed
By default, Linux suspends when the lid closes. `install.sh` sets this automatically, but you can also configure it manually:
1. Edit `/etc/systemd/logind.conf`:
   ```ini
   HandleLidSwitch=ignore
   HandleLidSwitchExternalPower=ignore
   HandleLidSwitchDocked=ignore
   ```
2. Apply changes:
   ```bash
   sudo systemctl restart systemd-logind.service
   ```

#### B. Disable Wi-Fi Power Saving (Low Latency UDP)
Wi-Fi cards often enter power-saving sleep after seconds of idle time, causing latency spikes or dropped UDP telemetry packets.
```bash
# Identify your wireless interface (e.g., wlan0, wlp2s0)
ip link

# Disable power saving
sudo iw dev wlan0 set power_save off
```
To make this persistent across reboots, add the command to `/etc/rc.local` or NetworkManager config.

#### C. Dim or Turn Off Laptop Screen
To conserve power and reduce heat with the lid open or closed:
```bash
# Turn off backlight on Linux console
sudo setterm --blank 1 --powerdown 1
```

---

## 4. Hardware Target 2: Raspberry Pi 4

The Raspberry Pi 4 (2 GB, 4 GB, or 8 GB) is a low-power (3–5 W) headless server platform.

### Key Raspberry Pi Optimizations:

#### A. Headless Initial Setup (Raspberry Pi Imager)
1. In **Raspberry Pi Imager**, select **Raspberry Pi OS (64-bit Lite)**.
2. Click the gear icon (Advanced Options) before writing to MicroSD:
   - Set hostname (e.g. `magnetometer-pi`).
   - Enable SSH (public-key or password).
   - Pre-configure your 2.4 GHz / 5 GHz Wi-Fi SSID & Password.
3. Power on the Pi. It connects to Wi-Fi automatically.
4. SSH into the Pi: `ssh <user>@magnetometer-pi.local`.

#### B. Protecting the MicroSD Card from Wear
1. **SQLite WAL Mode (Default)**: The central server runs SQLite with `PRAGMA journal_mode=WAL;` and batch commits, minimizing random write cycles.
2. **Periodic Backups**: Run `./manage.sh backup` via a nightly cron job:
   ```cron
   0 3 * * * /home/pi/remote_3_axis_magnetometer/central_service/manage.sh backup > /dev/null 2>&1
   ```
3. **Optional Log2Ram**: Install `log2ram` to write system logs to RAM instead of the SD card:
   ```bash
   echo "deb [signed-by=/usr/share/keyrings/azlux-archive-keyring.gpg] http://packages.azlux.fr/debian/ bookworm main" | sudo tee /etc/apt/sources.list.d/azlux.list
   sudo apt-get update && sudo apt-get install log2ram
   ```
4. **USB Boot (Recommended for Long-Term Deployments)**: Booting the Pi 4 directly from a cheap USB 3.0 SSD / NVMe enclosure eliminates SD card corruption risk entirely.

#### C. Static Local IP (DHCP Reservation)
To ensure the Pi always has the same IP on your home router:
- Log in to your home router (e.g., `http://192.168.1.1`).
- Go to **DHCP Settings / Address Reservation**.
- Bind the MAC address of the Raspberry Pi to a static IP (e.g., `192.168.1.100`).

---

## 5. Alternative Deployment: Docker Compose

If you prefer containerized deployment:

```bash
cd central_service

# Start central server in background
docker compose up -d

# Check status and logs
docker compose ps
docker compose logs -f

# Start both server and UDP edge gateway (host network mode)
docker compose --profile all up -d
```

Persistent SQLite database data is stored in the local `./data` directory on the host.

---

## 6. Accessing the Server Behind a Residential NAT

Residential ISPs place home connections behind NAT or Carrier-Grade NAT (CGNAT). To view your live dashboard or stream data from remote field sensor nodes:

👉 Run the interactive setup tool:
```bash
cd central_service
./remote_access.sh
```

Select **Option 1 (Cloudflare Tunnels)** to set up a zero-config outbound tunnel. This creates a secure `https://mag.yourdomain.com` endpoint with free SSL that allows any remote field node or web browser to connect **with zero client-side VPN software required**.

See the complete [**Residential NAT & Remote Access Guide**](NAT_AND_REMOTE_ACCESS.md) and the [**Secrets Management & System Security Guide**](SECRETS_AND_SECURITY.md) for full step-by-step setup instructions.

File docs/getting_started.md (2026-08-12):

# Getting Started & System Overview (`docs/getting_started.md`)

This guide covers system prerequisites, Conda environment setup, python dependency installation, and a quickstart deployment procedure.

---

## 1. Prerequisites & Conda Environment Setup

### System Requirements
- **Host OS**: Linux (Ubuntu/Debian), macOS, or Windows
- **Python**: Python 3.10+
- **PlatformIO CLI**: Installed via `pip install platformio` or VS Code PlatformIO extension

### Installation Commands

```bash
# Clone the repository
git clone https://github.com/morgatron/remote_3_axis_magnetometer.git
cd remote_3_axis_magnetometer

# Create and activate Conda environment
conda env create -f environment.yml
conda activate rm3100
```

`environment.yml` includes all necessary dependencies (`fastapi`, `uvicorn`, `requests`, `pySide6`, `pyqtgraph`, `pandas`, `pyarrow`, `h5py`, `bleak`, `platformio`).

---

## 2. Supported Hardware Target Boards

The system supports multiple hardware configurations managed via [`include/board_config.h`](../include/board_config.h) and [`platformio.ini`](../platformio.ini):

1. **Heltec WiFi LoRa 32 V4 (ESP32-S3 + SX1262 LoRa)**:
   - Built-in sub-GHz SX1262 LoRa radio (+22 dBm).
   - Integrated 3.7V LiPo battery management circuit.
   - Vext power gating rail (GPIO 36).
2. **ESP32-C6 RISC-V PCB**:
   - Native Wi-Fi 6 (802.11ax) with Target Wake Time (TWT) for battery nodes.
   - Bluetooth 5.3 LE Long Range (Coded PHY S=8).
   - 802.15.4 radio (Thread / Zigbee support).
3. **ESP32-C3 RISC-V PCB**:
   - Ultra-compact single-core RISC-V board.
   - Native USB CDC serial.

---

## 3. End-to-End 5-Minute Quickstart

### Step 1: Start the Central Data Server
```bash
cd central_service
python server.py
```
Open `http://localhost:8000` in your web browser.

### Step 2: Flash & Connect the Gateway Receiver Node
Plug your receiver ESP32 (e.g. Heltec V4 or ESP32-C6) into USB-C:
```bash
pio run -e heltec_v4_receiver -t upload --upload-port /dev/ttyACM1
```

### Step 3: Run the Edge Relay Gateway Service
```bash
cd central_service
python gateway.py
```

### Step 4: Flash & Deploy Remote Sensor Node(s)
Plug your field sensor ESP32 into USB-C:
```bash
pio run -e esp32-c3-devkitm-1 -t upload --upload-port /dev/ttyACM0
```
By default, the sensor node boots in **Low-Power LE Coded PHY Batch Mode with Hardware ACKs** (`MODE BLE`, `BATCH 10`).

### Step 5: Configure BLE Batch Burst Rate via CLI
Connect to the Sensor Node CLI (`pio device monitor -p /dev/ttyACM0 -b 921600`) to customize batching:
```text
BATCH 10      # 10 samples per burst (10s sleep, maximum power savings)
BATCH 1       # 1 sample per burst (instantaneous 1 Hz streaming)
STATUS        # Confirm Device ID, sensor type, and BLE batch size
```

### Step 6: Verify Active Node Metrics
Open the Receiver Gateway CLI (`pio device monitor -p /dev/ttyACM1 -b 921600`) and type:
```text
NODES
```
You will see your active remote field sensor listed with MAC address, signal RSSI (dBm), battery voltage ($V_{bat}$), and total packet count.

---

## 4. Primary Field Operational Mode (BLE 5.0 Long Range + Hardware ACK)

The system's **primary operational mode** utilizes **Bluetooth 5.0 Extended Advertising (LE Coded PHY S=8)** with **Hardware ACKs (`AUX_SCAN_REQ`)**:

1. **Long-Range Penetration**: LE Coded PHY S=8 provides **+12 dB sensitivity gain** (~4x range multiplier over standard BLE) at **+15 dBm Max Power**.
2. **Duty Cycle Power Savings**: The sensor buffers 1 Hz telemetry in SRAM and powers on its BLE transmitter for only **200 ms every 10 seconds** (`BATCH 10`), reducing RF duty cycle to **< 0.5%** (~35 to 45 days battery life).
3. **Hardware ACKs & Disconnect Buffer**: The receiver automatically sends a 1-byte hardware `AUX_SCAN_REQ` upon packet reception. If the receiver goes out of range, the sensor retains up to **600 samples (10 Minutes of history)** in SRAM, automatically flushing the backlog once re-connected.
4. **Standalone Field Access Point (SoftAP) Provisioning**: For Wi-Fi field setups without a router, the Gateway Receiver SoftAP broadcasts `MAG_GATEWAY_XXXX` on `192.168.4.1`. Remote nodes can be provisioned using:
   ```bash
   python provision_node.py --port /dev/ttyACM0 --sensor MOCK --mode BOTH --ssid "MAG_GATEWAY_XXXX" --pass magnetometer123 --target 192.168.4.1
   ```

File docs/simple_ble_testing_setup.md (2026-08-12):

# Simple BLE Coded PHY Low-Power Testing Guide (Mock Data Mode)

This guide provides simple, step-by-step instructions to flash, provision, and verify the **Low-Power Bluetooth 5.0 LE Coded PHY Batching Configuration** using synthetic **MOCK sensor mode** (no physical RM3100 or FLC100 sensor hardware required).

---

## Hardware Requirements & Port Assumptions

* **1x Field Sensor Node**: ESP32-C3 DevKit (connected to `/dev/ttyACM1`) or Heltec V4.
* **1x Gateway Receiver Node**: Heltec V4 ESP32-S3 (connected to `/dev/ttyACM0`) or ESP32-C6.
* **1x USB Micro-B or USB-C Cable per device**.

---

## Step 1: Flash Firmware

Open a terminal in the root repository directory and flash both nodes:

```bash
# 1. Flash Field Sensor Node Firmware (Port /dev/ttyACM1)
pio run -e esp32-c3-devkitm-1 -t upload --upload-port /dev/ttyACM1

# 2. Flash Gateway Receiver Node Firmware (Port /dev/ttyACM0)
pio run -e heltec_v4_receiver -t upload --upload-port /dev/ttyACM0
```

> [!NOTE]
> If using Heltec V4 for the sensor node instead of ESP32-C3, use `-e heltec_v4_sensor`.

---

## Step 2: Provision & Configure Sensor Node (MOCK Mode)

Configure the Sensor Node over USB Serial (`/dev/ttyACM1` at 921,600 baud) to run synthetic **MOCK mode** with 10-sample low-power BLE batching:

### Command Sequence (Send via Serial Terminal or Python):
```text
SENSOR MOCK
ID NODE_3A
BATCH 10
MODE BOTH
STREAM ON
SAVE
```

### Explanation of Commands:
* **`SENSOR MOCK`**: Switches from physical SPI hardware to synthetic 3-axis magnetic field generator (3-phase sine wave in Nanotesla).
* **`ID NODE_3A`**: Assigns canonical `NODE_*` device ID prefix.
* **`BATCH 10`**: Configures 10-sample 10-second low-power batch burst mode (radio stays 100% OFF for 9.7s out of every 10s).
* **`MODE BOTH`**: Enables both USB Serial output and Bluetooth 5.0 LE Coded PHY Extended Advertising.
* **`STREAM ON`**: Enables continuous 1 Hz downsampled telemetry acquisition.
* **`SAVE`**: Persists settings to NVS Flash memory so the node powers up in this mode automatically across reboots.

---

## Step 3: Provision & Configure Receiver Node

Configure the Receiver Node over USB Serial (`/dev/ttyACM0` at 921,600 baud):

### Command Sequence:
```text
MODE SERIAL
SAVE
```

### Explanation of Commands:
* **`MODE SERIAL`**: Routes received remote sensor telemetry out to USB Serial CDC (921,600 baud) for Python script / gateway forwarding.
* **`SAVE`**: Persists egress configuration to NVS Flash memory.

---

## Step 4: Verification Methods

### Option A: Run Automated Multi-Device Integration Test
Run the end-to-end multi-device test suite:

```bash
python3 test/test_integration_sensor_receiver.py --sensor-port /dev/ttyACM1 --rcvr-port /dev/ttyACM0
```

**Expected Output**:
```text
--- Test 01: 10-Sample Coded PHY Batch Reception ---
Total samples received over 22s: 10
Verified 9 consecutive 1.0s batch intervals inside burst
.
--- Test 02: Disconnect Ring Buffer Catch-up Flushing ---
Sensor switched to MODE SERIAL (simulating 22s offline disconnect)...
Switching sensor back to MODE BOTH to trigger catch-up flush...
Total catch-up samples received: 10
.
--- Test 03: Dynamic Batch Size Change (BATCH 5) ---
Total samples received under BATCH 5: 10
.
----------------------------------------------------------------------
Ran 3 tests in 87.547s

OK
```

---

### Option B: Monitor Live Telemetry Stream via Python

Run a live monitor script on the Receiver port (`/dev/ttyACM0`):

```bash
python3 -c "
import serial, time
s = serial.Serial('/dev/ttyACM0', 921600, timeout=1.0)
print('Monitoring Receiver for LE Coded PHY batch bursts...')
while True:
    line = s.readline().decode('utf-8', errors='ignore').strip()
    if line.startswith('NODE_'):
        print('Rx Telemetry:', line)
"
```

**Expected Telemetry Stream Output**:
```text
Rx Telemetry: NODE_3A,20935000,21623.00,-3162.00,43222.00,004D4F,0.0,3.30,-42
Rx Telemetry: NODE_3A,21935000,21420.00,-3250.00,43233.00,004D4F,0.0,3.30,-42
Rx Telemetry: NODE_3A,22935000,21180.00,-3310.00,43210.00,004D4F,0.0,3.30,-42
...
```

Notice that every 10 seconds, a burst of 10 samples arrives with timestamps spaced exactly 1.0 second apart (`1000000 µs`), and the Receiver OLED screen `Rx Pkts` counter increments by +10.

---

## Step 5: Test Disconnect Catch-Up & Sensor Reboot Recovery

### 1. Offline Disconnect Catch-Up Test:
1. Send `MODE SERIAL` to the sensor on `/dev/ttyACM1` (disables BLE advertising, simulating an out-of-range disconnect).
2. Wait 20 seconds while the sensor accumulates 20 samples in its SRAM ring buffer.
3. Send `MODE BOTH` to the sensor on `/dev/ttyACM1`.
4. **Observation**: The sensor immediately transmits consecutive 300ms bursts back-to-back, flushing all 20 buffered catch-up samples to the receiver in ~1.5 seconds!

### 2. Sensor Reboot Recovery Test:
1. Send `REBOOT` to the sensor on `/dev/ttyACM1`.
2. **Observation**: The sensor restarts and sends post-reboot bursts. The receiver automatically detects the timestamp reset (`start_ts_ms < last_sample_ts_ms`), clears its de-duplication table, and continues receiving valid telemetry without freezing or locking up.

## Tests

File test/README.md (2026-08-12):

# Hardware & Low-Power Telemetry Test Suite

This directory contains automated test suites to verify firmware functionality, C-struct binary serialization, CLI commands, and low-power telemetry power management across both host environments and physical single-device hardware setups.

---

## 1. Test Suite Summary

| Test Script | Target | Requires Hardware? | Description |
| :--- | :--- | :--- | :--- |
| `test/test_batch_serialization.py` | Host PC | **NO** | Validates 139-byte `SensorBatchPacket` struct memory alignment, compact sample packing (`CompactSample`), and microsecond relative timestamp reconstruction logic. |
| `test/test_receiver_parser.py` | Host PC | **NO** | Validates CSV parsing and timestamp back-calculation via `stream_parser.py`. |
| `test/test_scaling_math.py` | Host PC | **NO** | Verifies on-board scale factor math invariance across dynamic cycle counts. |
| `test/test_sensor_standalone.py` | Sensor Node | **YES** (`/dev/ttyACM0`) | Verifies single sensor node CLI commands (`BATCH 1..10`, `STATUS`), NVS Flash persistence, and sub-microsecond `DRDY` interrupt timestamp jitter under DFS. |
| `test/test_receiver_standalone.py` | Receiver Node | **YES** (`/dev/ttyACM1`) | Verifies single gateway receiver node CLI commands (`STATUS`, `NODES`, `MODE`), 80 MHz CPU scaling, and active node tracking. |
| `test/test_integration_sensor_receiver.py` | Sensor + Receiver | **YES** (`/dev/ttyACM0` + `/dev/ttyACM1`) | Verifies end-to-end Bluetooth 5.0 LE Coded PHY Extended Advertising batching (`BATCH 10` vs `BATCH 5`), hardware `AUX_SCAN_REQ` ACKs, and 10-minute disconnect ring buffer catch-up flushing. |

---

## 2. Running the Tests

### Host Unit Tests (No Hardware Required)
```bash
python -m unittest test/test_batch_serialization.py
python -m unittest test/test_receiver_parser.py
python test/test_scaling_math.py
```

### Standalone Single-Device Hardware Tests
```bash
# Sensor Node Hardware Self-Test (single device on /dev/ttyACM0)
python test/test_sensor_standalone.py --port /dev/ttyACM0

# Receiver Node Hardware Self-Test (single device on /dev/ttyACM1)
python test/test_receiver_standalone.py --port /dev/ttyACM1
```

### End-to-End Multi-Device Integration Test
```bash
# End-to-End Batching & Catch-up Flush Test (Sensor on /dev/ttyACM0, Receiver on /dev/ttyACM1)
python test/test_integration_sensor_receiver.py --sensor-port /dev/ttyACM0 --rcvr-port /dev/ttyACM1
```

### Full Automated Test Suite Execution
```bash
python test/test_batch_serialization.py && \
python test/test_sensor_standalone.py --port /dev/ttyACM0 && \
python test/test_receiver_standalone.py --port /dev/ttyACM1 && \
python test/test_integration_sensor_receiver.py --sensor-port /dev/ttyACM0 --rcvr-port /dev/ttyACM1
```

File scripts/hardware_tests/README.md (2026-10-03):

# Hardware Diagnostic & Manual Test Scripts

This directory contains standalone, manual hardware test scripts and diagnostics designed to be run against physically connected ESP32 boards via USB serial or local network interfaces.

Unlike unit and host integration tests in `test/`, these scripts are not run as part of automated CI/test discovery.

---

## Script Index

| Script | Interface | Target / Description |
| :--- | :--- | :--- |
| `test_hardware.py` | Serial (`/dev/ttyUSB*`, `/dev/ttyACM*`) | Pytest-based interactive test verifying CLI commands (`HELP`, `STATUS`, `STREAM ON/OFF`) and CSV stream format. Requires `pytest`. |
| `test_raw_spikes.py` | Serial (`/dev/ttyUSB0`, 921600 baud) | Monitors raw ASCII magnetometer stream to detect single-axis sudden deltas/spikes (>40 nT). |
| `test_wifi_connect.py` | Serial (`/dev/ttyUSB0`, 921600 baud) | Sends Wi-Fi connection and target IP configuration commands to an attached gateway node. |
| `test_wifi_provision.py` | Serial (`/dev/ttyUSB0`, 921600 baud) | Queries Wi-Fi status and system status from an attached gateway node. |
| `test_udp_listen.py` | Network (UDP port 9876) | Binds to local UDP port 9876 and logs received magnetometer telemetry packets broadcast over Wi-Fi. |

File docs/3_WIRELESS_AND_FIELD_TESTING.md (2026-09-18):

# 3. Wireless & Field Testing Guide

This guide covers field range verification, signal strength monitoring (RSSI), and phone/laptop client setup using Bluetooth 5.0 LE Coded PHY and LoRa.

---

## 1. Monitoring Telemetry on a Phone (nRF Connect)

The receiver gateway broadcasts connectionless 1 Mbps BLE **Extended Advertising** auxiliary PDUs under Company ID `0xFFFF` (`b"MG"`).

### Step-by-Step Instructions:
1. Open **nRF Connect** (Android / iOS) and go to the **Scanner** tab.
2. In the scanner filter, look for advertisements or raw manufacturer data from **`MAG_GATEWAY`** (or Company ID `0xFFFF`).
3. Tap on the advertised packet to view details:
   * **Manufacturer Data:** Contains the 31-byte `GatewayAdvPacket` header (33 bytes including 2-byte company ID) followed by 12-byte compact $(X, Y, Z)$ sensor samples.
   * **Company ID:** `0xFFFF` (Test/Custom)
   * **Payload Format:** Unpacked automatically by `scripts/ble_monitor.py` or nRF Connect raw payload inspector.
4. Every 10 seconds, the receiver emits a 1-second burst containing up to 18 samples from the remote sensor node.

---

## 2. Reading Link Signal Strength (RSSI)

There are two distinct signal strength metrics:

### A. Sensor-to-Gateway Link (Long-Range BLE Coded PHY / LoRa)
* **Where to find it:** The **9th (last) number** in every CSV line (e.g. `-45` in the sample above).
* **Evaluation Scale:**
  * **$-30\text{ to }-60\text{ dBm}$:** Excellent signal (close range).
  * **$-70\text{ to }-85\text{ dBm}$:** Good outdoor field signal.
  * **$-90\text{ to }-105\text{ dBm}$:** Fringe coverage limit.

### B. Gateway-to-Phone Link (Standard 1M BLE)
* In nRF Connect, tap the **three vertical dots $\mathbf{\vdots}$** in the top right $\to$ **Read RSSI** (or **Show RSSI graph**).

---

## 3. Laptop Telemetry & Diagnostic Monitor (`ble_monitor.py`)

Run the Python BLE connectionless scanner on Linux, macOS, or Windows. It passively listens for 1 Mbps Extended Advertising auxiliary PDUs from the receiver gateway without establishing a GATT connection or requiring pairing, or connects to an ESP32 BLE-to-serial bridge:

```bash
# Live stream to terminal (passive scanner)
python3 scripts/ble_monitor.py

# Live stream via hardware ESP32-C3 USB serial bridge
python3 scripts/ble_monitor.py --serial /dev/ttyACM2

# Collect N samples and exit cleanly
python3 scripts/ble_monitor.py --max-samples 40

# Run for a specific duration in seconds
python3 scripts/ble_monitor.py --timeout 45

# Save stream to CSV file
python3 scripts/ble_monitor.py --csv garden_session.csv

# Forward directly to Central Server HTTP endpoint
python3 scripts/ble_monitor.py --forward-url http://localhost:8000/api/v1/telemetry
```

### Gateway Diagnostic & Rendezvous Event Decoding
The gateway broadcasts real-time diagnostic packets (`sample_count == 0`) which `ble_monitor.py` parses automatically:
* **`[GATEWAY HEARTBEAT]`**: Emitted every 60s when idle, reporting gateway battery voltage and active tracking state.
* **`[GATEWAY STATUS] SYNC_ACQUIRED`**: Emitted upon locking to a remote sensor, reporting discovery duration in milliseconds.
* **`[GATEWAY ALERT] WINDOW_MISSED`**: Emitted when an expected burst window times out, reporting consecutive miss count and on-time.
* **`[GATEWAY ALERT] LOST_SYNC_DISCOVERY`**: Emitted after 3 consecutive misses, indicating the receiver has transitioned to discovery mode.
* **`[GATEWAY NOTICE] PERIODIC_LOOKOUT`**: Emitted during the 10-minute periodic scan for new field nodes.

---

## 4. Range Testing Utility (`rssi_monitor.py`)

To log and graph RSSI versus distance during outdoor walk tests:

```bash
python3 scripts/rssi_monitor.py --port /dev/ttyACM0 --output range_test.csv
```

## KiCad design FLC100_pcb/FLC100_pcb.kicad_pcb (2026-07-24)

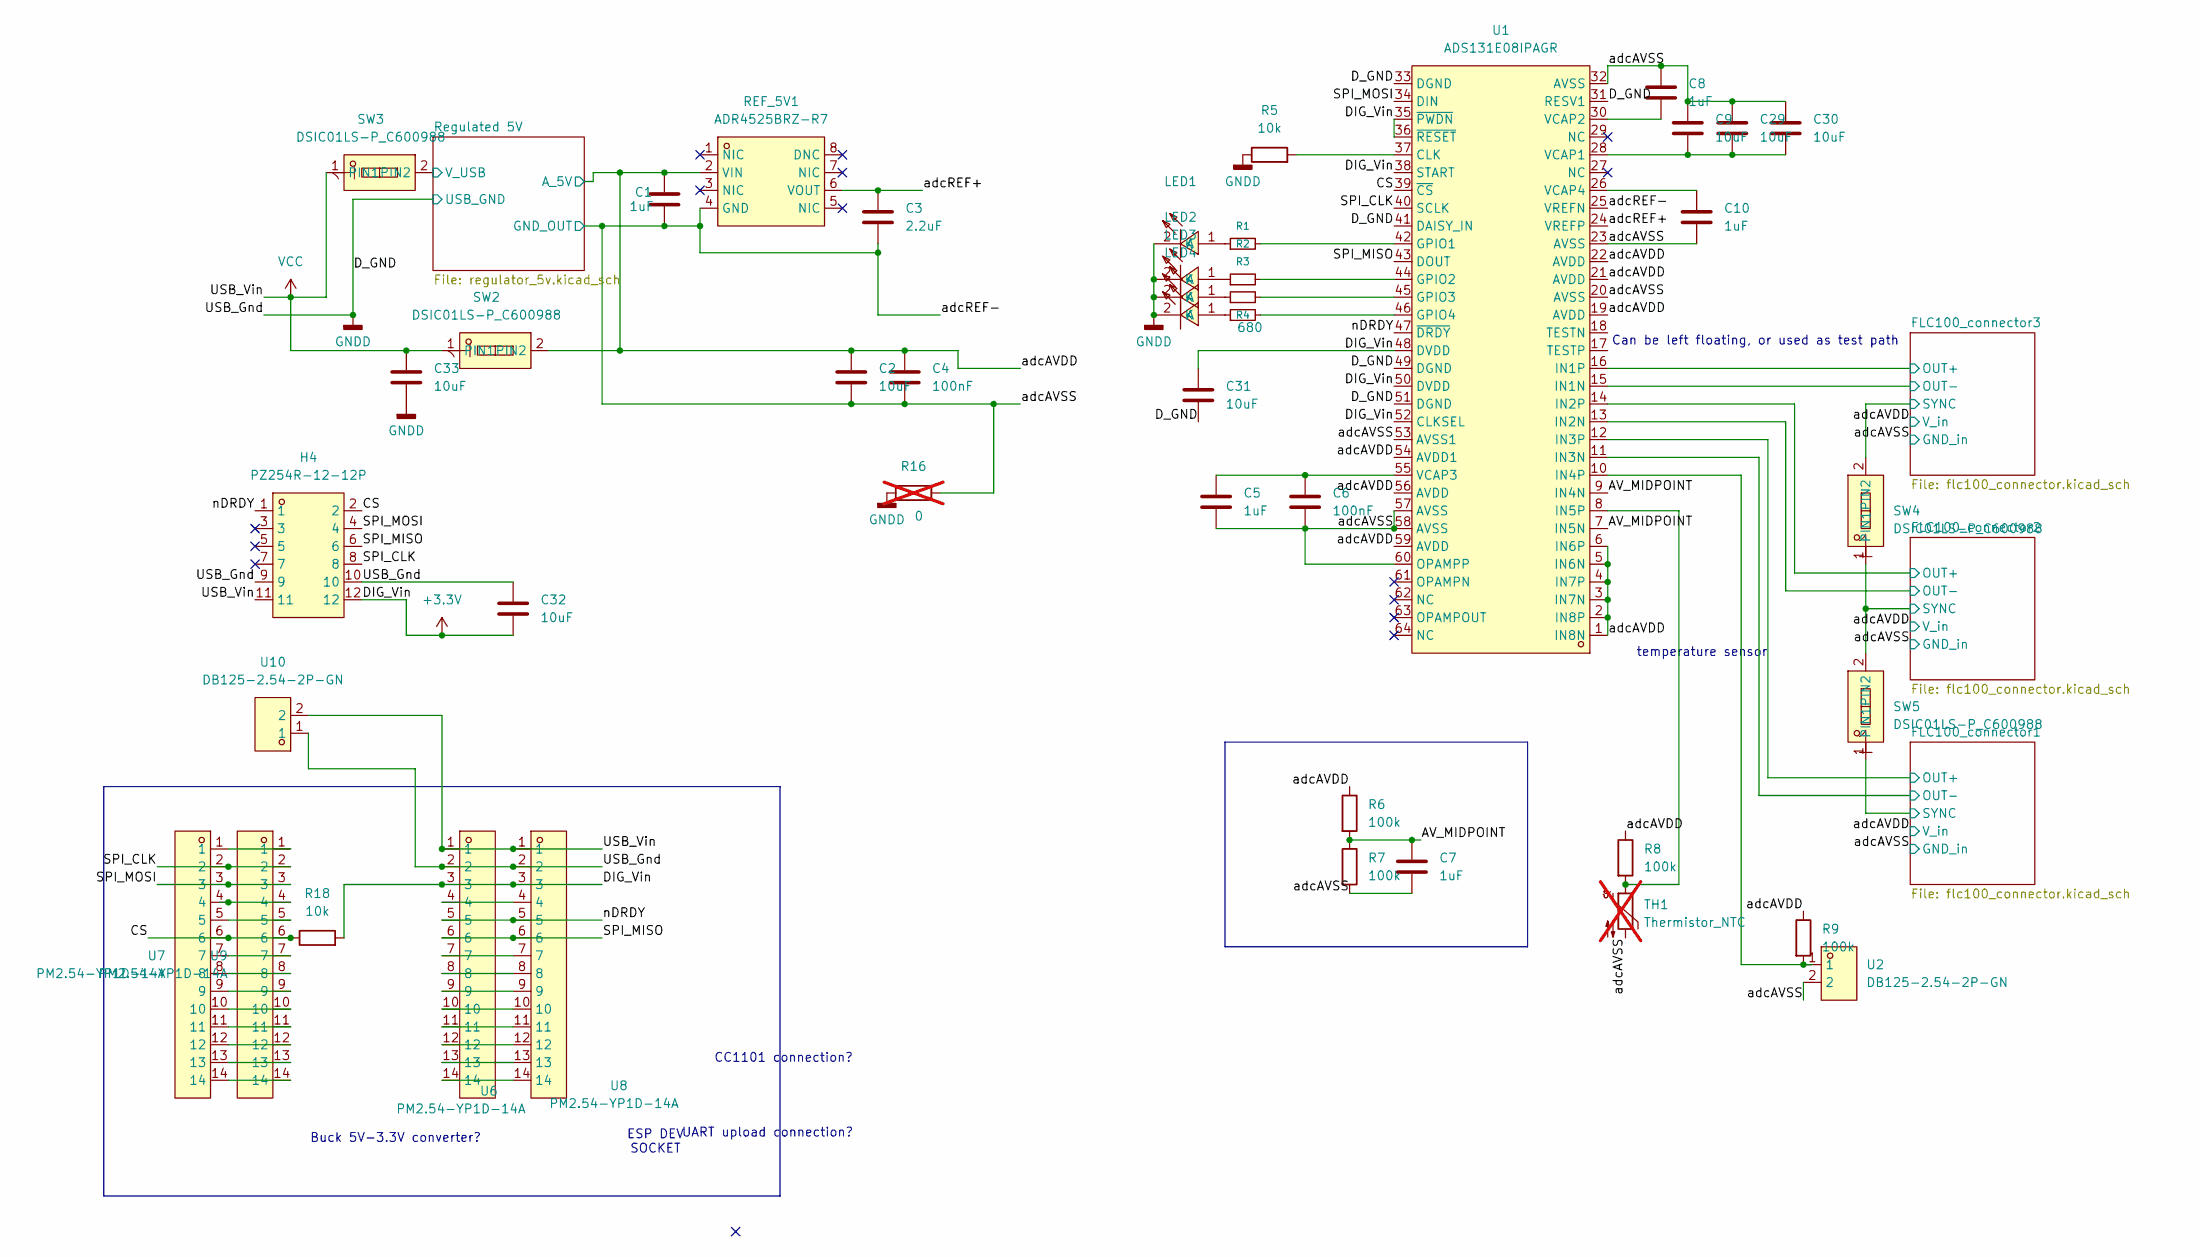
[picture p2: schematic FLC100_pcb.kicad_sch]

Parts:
C1, C5, C7, C8, C10: 1uF; C_0603_1608Metric
C2, C9, C29, C30, C31, C32, C33: 10uF; C_0603_1608Metric
C3: 2.2uF; C_0603_1608Metric
C4, C6: 100nF; C_0402_1005Metric
H4: PZ254R-12-12P; HDR-TH_12P-P2.54-H-M-R2-C6-S2.54; MPN PZ254R-12-12P; LCSC Part C492434
LED1, LED2, LED3, LED4: 0603White light_C2290; LED0603-R-RD_WHITE; MPN KT-0603W; LCSC Part C2290
R1, R2, R3, R4: 680; R_0603_1608Metric
R5, R18: 10k; R_0402_1005Metric
R6, R7, R8, R9: 100k; R_0805_2012Metric
R16: 0; R_0805_2012Metric; not fitted
REF_5V1: ADR4525BRZ-R7; SOIC-8_L4.9-W3.9-P1.27-LS6.0-BL; MPN ADR4525BRZ-R7; LCSC Part C403914
SW2, SW3, SW4, SW5: DSIC01LS-P_C600988; SW-SMD_2P-L3.5-W6.1-P2.54-LS9.8; MPN DSIC01LS-P; LCSC Part C600988
TH1: Thermistor_NTC; R_Axial_DIN0204_L3.6mm_D1.6mm_P2.54mm_Vertical; not fitted
U1: ADS131E08IPAGR; LQFP-64_L10.0-W10.0-P0.50-LS12.0-TL; MPN ADS131E08IPAGR; LCSC Part C190276
U2, U10: DB125-2.54-2P-GN; CONN-TH_DB125-2.54-2P-GN; MPN DB125-2.54-2P-GN-S; LCSC Part C918120
U6, U7, U8, U9: PM2.54-YP1D-14A; HDR-TH_14P-P2.54-V-F-2; MPN PM2.54-YP1D-14A; LCSC Part C22399554

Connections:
+3.3V: C31.1, C32.2, H4.12, R18.2, U1.35 (~PWDN), U1.36 (~RESET), U1.38 (START), U1.48 (DVDD), U1.50 (DVDD), U1.52 (CLKSEL), U6.3, U8.3
/AV_MIDPOINT: C7.1, R6.2, R7.1, U1.7 (IN5N), U1.9 (IN4N)
/CS: H4.2, R18.1, U1.39 (~CS), U7.6, U9.6
/FLC100_connector1/OUT+: U1.12 (IN3P); also elsewhere on the board
/FLC100_connector1/OUT-: U1.11 (IN3N); also elsewhere on the board
/FLC100_connector1/SYNC: SW5.1 (PIN1); also elsewhere on the board
/FLC100_connector2/OUT+: U1.14 (IN2P); also elsewhere on the board
/FLC100_connector2/OUT-: U1.13 (IN2N); also elsewhere on the board
/FLC100_connector2/SYNC: SW4.1 (PIN1), SW5.2 (PIN2); also elsewhere on the board
/FLC100_connector3/OUT+: U1.16 (IN1P); also elsewhere on the board
/FLC100_connector3/OUT-: U1.15 (IN1N); also elsewhere on the board
/FLC100_connector3/SYNC: SW4.2 (PIN2); also elsewhere on the board
/Regulated 5V/V_USB: SW3.2 (PIN2); also elsewhere on the board
/SPI_CLK: H4.8, U1.40 (SCLK), U7.2, U9.2
/SPI_MISO: H4.6, U1.43 (DOUT), U6.6, U8.6
/SPI_MOSI: H4.4, U1.34 (DIN), U7.3, U9.3
/adcAVDD: C1.1, C2.1, C4.1, R6.1, R8.1, R9.1, REF_5V1.2 (VIN), SW2.2 (PIN2), U1.1 (IN8N), U1.2 (IN8P), U1.3 (IN7N), U1.4 (IN7P), U1.5 (IN6N), U1.6 (IN6P), U1.19 (AVDD), U1.21 (AVDD), U1.22 (AVDD), U1.54 (AVDD1), U1.56 (AVDD), U1.59 (AVDD); also elsewhere on the board
/adcAVSS: C1.2, C2.2, C3.2, C4.2, C5.2, C6.2, C7.2, C8.1, C9.1, C10.2, C29.1, C30.1, R7.2, R16.2, REF_5V1.4 (GND), TH1.2, U1.20 (AVSS), U1.23 (AVSS), U1.25 (VREFN), U1.32 (AVSS), U1.53 (AVSS1), U1.57 (AVSS), U1.58 (AVSS), U1.60 (OPAMPP), U2.2; also elsewhere on the board
/adcREF+: C3.1, REF_5V1.6 (VOUT), U1.24 (VREFP)
/nDRDY: H4.1, U1.47 (~DRDY), U6.5, U8.5
GNDD: C31.2, C32.1, C33.2, H4.9, H4.10, LED1.2 (K), LED2.2 (K), LED3.2 (K), LED4.2 (K), R5.1, R16.1, U1.31 (RESV1), U1.33 (DGND), U1.41 (DAISY_IN), U1.49 (DGND), U1.51 (DGND), U6.2, U8.2, U10.1; also elsewhere on the board
unnamed: LED1.1 (A), R1.1
unnamed: LED2.1 (A), R2.1
unnamed: LED3.1 (A), R3.1
unnamed: LED4.1 (A), R4.1
unnamed: R5.2, U1.37 (CLK)
unnamed: R1.2, U1.42 (GPIO1)
unnamed: R2.2, U1.44 (GPIO2)
unnamed: R3.2, U1.45 (GPIO3)
unnamed: R4.2, U1.46 (GPIO4)
unnamed: R9.2, U1.10 (IN4P), U2.1
unnamed: R8.2, TH1.1, U1.8 (IN5P)
unnamed: C9.2, C29.2, C30.2, U1.28 (VCAP1)
unnamed: C8.2, U1.30 (VCAP2)
unnamed: C5.1, C6.1, U1.55 (VCAP3)
unnamed: C10.1, U1.26 (VCAP4)
unnamed: U6.4, U8.4
unnamed: U6.7, U8.7
unnamed: U6.8, U8.8
unnamed: U6.9, U8.9
unnamed: U6.10, U8.10
unnamed: U6.11, U8.11
unnamed: U6.12, U8.12
unnamed: U6.13, U8.13
unnamed: U6.14, U8.14
unnamed: U7.1, U9.1
unnamed: U7.4, U9.4
unnamed: U7.5, U9.5
unnamed: U7.7, U9.7
unnamed: U7.8, U9.8
unnamed: U7.9, U9.9
unnamed: U7.10, U9.10
unnamed: U7.11, U9.11
unnamed: U7.12, U9.12
unnamed: U7.13, U9.13
unnamed: U7.14, U9.14
VCC: C33.1, H4.11, SW2.1 (PIN1), SW3.1 (PIN1), U6.1, U8.1, U10.2

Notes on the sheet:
Can be left floating, or used as test path
CC1101 connection?
ESP DEV SOCKET
Buck 5V-3.3V converter?
temperature sensor
UART upload connection?

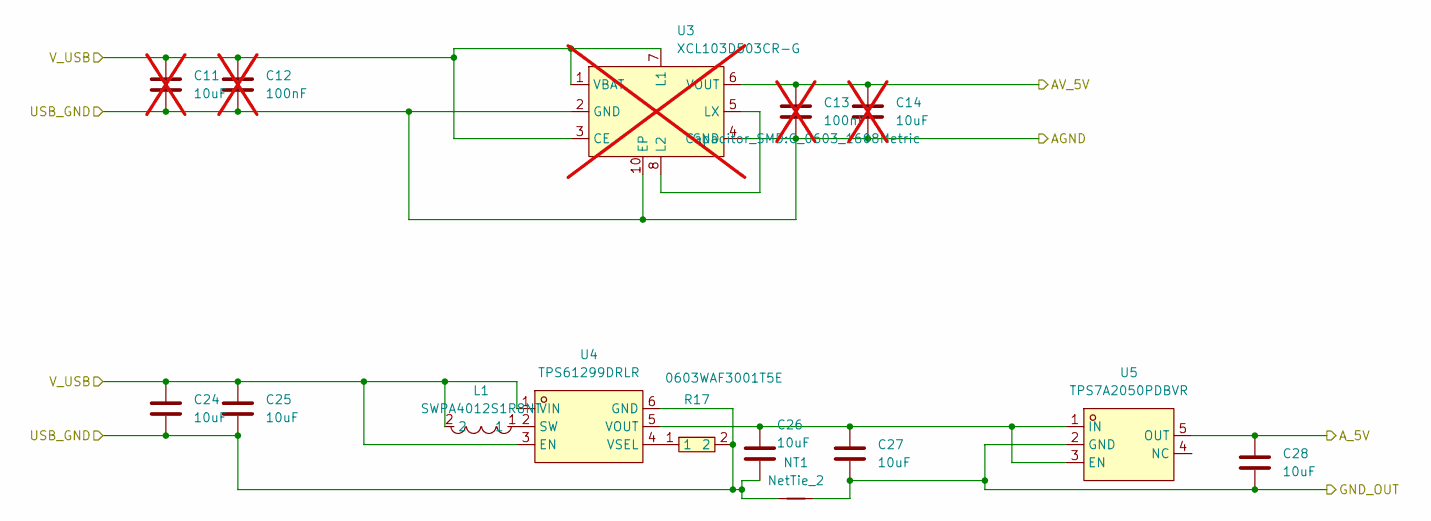
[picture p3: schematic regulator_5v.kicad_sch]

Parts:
C11, C14: 10uF; C_0603_1608Metric; not fitted
C12, C13: 100nF; C_0603_1608Metric; not fitted
C24, C25, C26, C27, C28: 10uF; C_0603_1608Metric
L1: SWPA4012S1R8NT; IND-SMD_L4.0-W4.0; MPN SWPA4012S1R8NT; LCSC Part C96867
NT1: NetTie_2; NetTie-2_SMD_Pad2.0mm
R17: 0603WAF3001T5E; R0603; MPN 0603WAF3001T5E; LCSC Part C4211
U3: XCL103D503CR-G; CL-2025-02_8P-L2.5-W2.0-P0.55_XCL210C331GR-G; MPN XCL103D503CR-G; LCSC Part C5439677; not fitted
U4: TPS61299DRLR; SOT-563-6_L1.6-W1.2-P0.50-LS1.6-BL; MPN TPS61299DRLR; LCSC Part C41689719
U5: TPS7A2050PDBVR; SOT-23-5_L2.9-W1.6-P0.95-LS2.8-BR; MPN TPS7A2050PDBVR; LCSC Part C2864504

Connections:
/Regulated 5V/V_USB: C11.1, C12.1, C24.1, C25.1, L1.2, U3.1 (VBAT), U3.3 (CE), U3.7 (L1), U4.1 (VIN), U4.3 (EN); also elsewhere on the board
/adcAVDD: C28.1, U5.5 (OUT); also elsewhere on the board
/adcAVSS: C27.2, C28.2, NT1.1, U5.2 (GND); also elsewhere on the board
GNDD: C11.2, C12.2, C13.2, C14.2, C24.2, C25.2, C26.2, NT1.2, R17.2, U3.2 (GND), U3.4 (GND), U3.10 (EP), U4.6 (GND); also elsewhere on the board
unnamed: C13.1, C14.1, U3.6 (VOUT)
unnamed: U3.5 (LX), U3.8 (L2)
unnamed: L1.1, U4.2 (SW)
unnamed: C26.1, C27.1, U4.5 (VOUT), U5.1 (IN), U5.3 (EN)
unnamed: R17.1, U4.4 (VSEL)

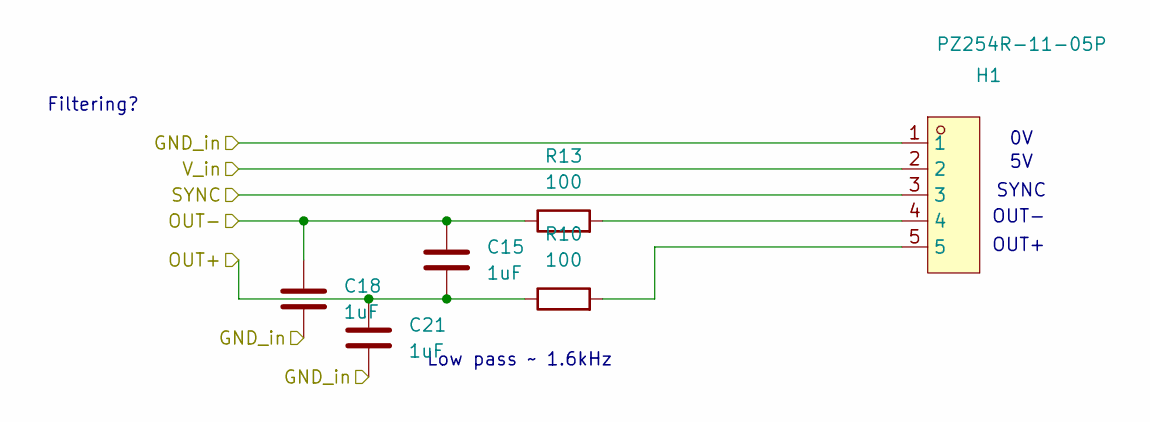
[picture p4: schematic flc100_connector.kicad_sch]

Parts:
C15, C18, C21: 1uF; C_0603_1608Metric
H1: PZ254R-11-05P; HDR-TH_5P-P2.54-H-M-W10.4; MPN PZ254R-11-05P; LCSC Part C492413
R10, R13: 100; R_0805_2012Metric

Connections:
/FLC100_connector1/OUT+: C15.2, C21.1, R10.1; also elsewhere on the board
/FLC100_connector1/OUT-: C15.1, C18.1, R13.1; also elsewhere on the board
/FLC100_connector1/SYNC: H1.3; also elsewhere on the board
/adcAVDD: H1.2; also elsewhere on the board
/adcAVSS: C18.2, C21.2, H1.1; also elsewhere on the board
unnamed: H1.4, R13.2
unnamed: H1.5, R10.2

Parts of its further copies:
C16, C17, C19, C20, C22, C23: 1uF; C_0603_1608Metric
H2, H3: PZ254R-11-05P; HDR-TH_5P-P2.54-H-M-W10.4; MPN PZ254R-11-05P; LCSC Part C492413
R11, R12, R14, R15: 100; R_0805_2012Metric

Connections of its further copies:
/FLC100_connector2/OUT+: C17.2, C23.1, R12.1; also elsewhere on the board
/FLC100_connector2/OUT-: C17.1, C20.1, R15.1; also elsewhere on the board
/FLC100_connector2/SYNC: H3.3; also elsewhere on the board
/FLC100_connector3/OUT+: C16.2, C22.1, R11.1; also elsewhere on the board
/FLC100_connector3/OUT-: C16.1, C19.1, R14.1; also elsewhere on the board
/FLC100_connector3/SYNC: H2.3; also elsewhere on the board
/adcAVDD: H2.2, H3.2; also elsewhere on the board
/adcAVSS: C19.2, C20.2, C22.2, C23.2, H2.1, H3.1; also elsewhere on the board
unnamed: H2.4, R14.2
unnamed: H2.5, R11.2
unnamed: H3.4, R15.2
unnamed: H3.5, R12.2

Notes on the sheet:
OUT-
Low pass ~ 1.6kHz
SYNC
OUT+
Filtering?

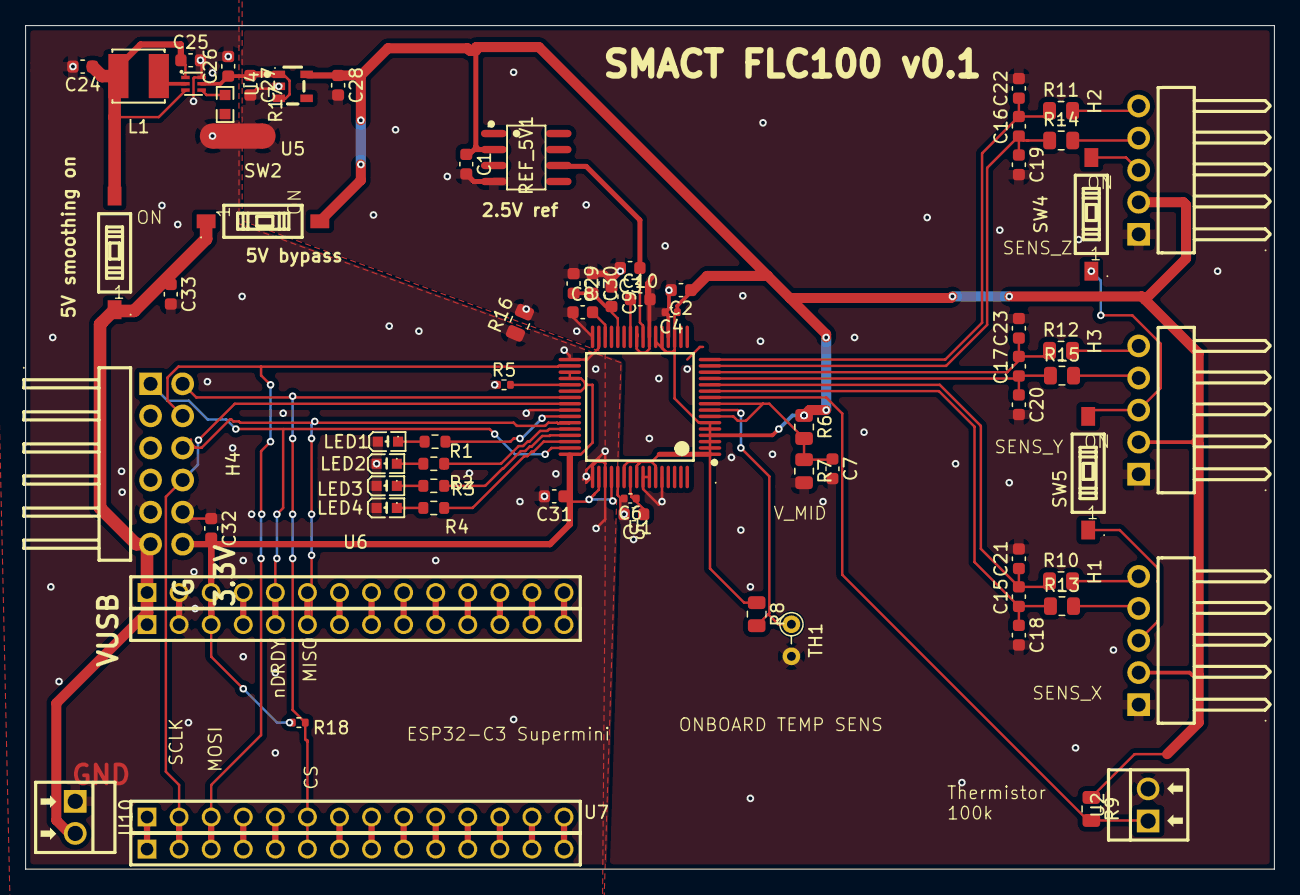
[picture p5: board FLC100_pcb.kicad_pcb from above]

Board: 2 copper layers, 98.9 x 66.8 mm, 72 parts (0 on the bottom side), 66 nets.

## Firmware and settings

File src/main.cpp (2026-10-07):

#include <Arduino.h>
#include <SPI.h>
#include <Preferences.h>
#include <esp_mac.h>
#include <esp_pm.h>
#include "board_config.h"
#include "TelemetryRingBuffer.h"

#include "RM3100.h"
#include "FLC100_ADS131.h"
#include "MockSensor.h"
#include "OLEDDisplay.h"

float g_cachedBatteryVoltage = 0.0f;

void configurePowerManagement();

RM3100 sensorRM3100(CS_PIN, DRDY_PIN);
FLC100_ADS131 sensorFLC100(CS_PIN, DRDY_PIN, RESET_PIN);
MockSensor sensorMock;

uint8_t sensorTypeConfig = 1; // 0 = RM3100, 1 = FLC100-ADS131E08, 2 = Mock Sensor
const uint8_t DEFAULT_RATE = 0x95;

#include "CLI.h"
#include <WiFi.h>
#include <WiFiUdp.h>

Preferences prefs;
Magnetometer* sensor = &sensorFLC100;

bool streaming = true;
uint8_t current_rate = DEFAULT_RATE;
uint16_t current_downsample = 1;
uint16_t cycleCountConfig = 200; // RM3100 cycle count (saved to NVS)

// WiFi & UDP Globals
WiFiUDP udp;
IPAddress targetIP(255, 255, 255, 255); // Default broadcast
uint16_t targetPort = 9876;
uint16_t udpListenPort = 9876;

#include "BLEStream.h"
#if defined(BOARD_HAS_LORA)
#include "LoRaStream.h"
#endif

#ifndef DEFAULT_OUTPUT_MODE
#define DEFAULT_OUTPUT_MODE MODE_BLE
#endif

enum OutputMode { MODE_SERIAL = 0, MODE_WIFI = 1, MODE_BOTH = 2, MODE_BLE = 3, MODE_LORA = 4 };
uint8_t outputMode = DEFAULT_OUTPUT_MODE;
uint8_t batchSizeConfig = 10; // Default: 10 samples per Coded PHY burst (range 1-10)
String wifiSSID = "";
String wifiPass = "";
bool wifiConnected = false;
String deviceID = "";

#if defined(ESP_PLATFORM)
portMUX_TYPE g_spiFrequencyMux = portMUX_INITIALIZER_UNLOCKED;

void safeSetCpuFrequencyMhz(uint32_t freq) {
    if (getCpuFrequencyMhz() == freq) return;
    portENTER_CRITICAL(&g_spiFrequencyMux);
    setCpuFrequencyMhz(freq);
    portEXIT_CRITICAL(&g_spiFrequencyMux);
}
#else
void safeSetCpuFrequencyMhz(uint32_t freq) {
    setCpuFrequencyMhz(freq);
}
#endif

void configurePowerManagement() {
#if defined(ESP_PLATFORM)
#if defined(CONFIG_IDF_TARGET_ESP32C6) || defined(ARDUINO_ARCH_ESP32C6)
    // ESP32-C6 Bluetooth baseband & hardware encryption controller require active PLL (minimum 80 MHz)
    safeSetCpuFrequencyMhz(80);
    Serial.printf("[POWER] ESP32-C6 Low-Power Mode: CPU @ %d MHz (PLL active, Modem OFF between bursts).\r\n", getCpuFrequencyMhz());
#else
    if (outputMode == MODE_BLE) {
        safeSetCpuFrequencyMhz(40);
        Serial.printf("[POWER] Low-Power BLE Mode: CPU @ %d MHz (Modem OFF between bursts).\r\n", getCpuFrequencyMhz());
    } else {
        safeSetCpuFrequencyMhz(80);
        Serial.printf("[POWER] CPU Frequency set to %d MHz (80MHz APB retained, zero SPI latency).\r\n", getCpuFrequencyMhz());
    }
#endif
#endif
}

void saveSettings() {
    prefs.begin("mcu_v0", false);
    prefs.putBool("streaming", streaming);
    prefs.putUChar("rate", current_rate);
    prefs.putUShort("downsample", current_downsample);
    prefs.putUChar("sensor_type", sensorTypeConfig);
    prefs.putUChar("mode", outputMode);
    prefs.putUChar("batch_size", batchSizeConfig);
    prefs.putUShort("cycle_count", cycleCountConfig);
    prefs.putString("ssid", wifiSSID);
    prefs.putString("pass", wifiPass);
    prefs.putString("target", targetIP.toString());
    prefs.putString("device_id", deviceID);
    prefs.end();
}

static char udpBatchBuf[4096];
static size_t udpBatchLen = 0;
static uint32_t lastUdpFlushMs = 0;

void flushUdpBatch() {
    if (udpBatchLen > 0 && wifiConnected) {
        udp.beginPacket(targetIP, targetPort);
        udp.write((const uint8_t*)udpBatchBuf, udpBatchLen);
        udp.endPacket();
        udpBatchLen = 0;
        lastUdpFlushMs = millis();
    }
}

void connectWiFi() {
    if (wifiSSID.length() > 0) {
        Serial.println("\r\n==========================================");
        Serial.print("[WIFI DEBUG] Initiating connection to SSID: '");
        Serial.print(wifiSSID);
        Serial.println("'...");

        WiFi.disconnect(true);
        delay(100);
        WiFi.mode(WIFI_STA);
        WiFi.setTxPower(WIFI_POWER_15dBm); // Cap TX power to 15dBm to prevent 3.3V power supply dips
        WiFi.begin(wifiSSID.c_str(), wifiPass.c_str());

        unsigned long start = millis();
        while (WiFi.status() != WL_CONNECTED && (millis() - start < 12000)) {
            delay(500);
            wl_status_t status = WiFi.status();
            Serial.print("[WIFI DEBUG] Connecting... State=");
            Serial.print((int)status);
            if (status == WL_NO_SSID_AVAIL) Serial.println(" (SSID Not Found in 2.4GHz scan)");
            else if (status == WL_CONNECT_FAILED) Serial.println(" (Connection Failed - Check Password)");
            else if (status == WL_DISCONNECTED) Serial.println(" (Associating...)");
            else Serial.println();
        }

        if (WiFi.status() == WL_CONNECTED) {
            wifiConnected = true;
            Serial.println("[WIFI SUCCESS] Connected to network!");
            Serial.print("  Local IP:    "); Serial.println(WiFi.localIP());
            Serial.print("  Subnet Mask: "); Serial.println(WiFi.subnetMask());
            Serial.print("  Gateway IP:  "); Serial.println(WiFi.gatewayIP());
            Serial.print("  RSSI Signal: "); Serial.print(WiFi.RSSI()); Serial.println(" dBm");
            Serial.print("  Target IP:   "); Serial.println(targetIP);
            udp.begin(udpListenPort);
            Serial.print("  UDP Active on Port "); Serial.println(udpListenPort);
            Serial.println("==========================================\r\n");
        } else {
            wifiConnected = false;
            Serial.println("[WIFI ERROR] Connection timed out after 12 seconds!");
            Serial.println("  Check SSID spelling, WPA2 password, or 2.4GHz band availability.");
            Serial.println("==========================================\r\n");
        }
    }
}

void loadSettings() {
    prefs.begin("mcu_v0", true);
    sensorTypeConfig = prefs.getUChar("sensor_type", 1);
    current_rate = prefs.getUChar("rate", DEFAULT_RATE);
    current_downsample = prefs.getUShort("downsample", (sensorTypeConfig == 1) ? 1000 : 1);
    outputMode = prefs.getUChar("mode", DEFAULT_OUTPUT_MODE);
    batchSizeConfig = prefs.getUChar("batch_size", 10);
    if (batchSizeConfig < 1 || batchSizeConfig > 10) batchSizeConfig = 10;
    cycleCountConfig = prefs.getUShort("cycle_count", 200);
    wifiSSID = prefs.getString("ssid", "");
    wifiPass = prefs.getString("pass", "");
    String tIP = prefs.getString("target", "255.255.255.255");
    targetIP.fromString(tIP);
    deviceID = prefs.getString("device_id", "");
    prefs.end();

    if (deviceID.length() == 0) {
#if defined(DEFAULT_DEVICE_ID)
        deviceID = String(DEFAULT_DEVICE_ID);
#else
        uint8_t mac[6];
        esp_read_mac(mac, ESP_MAC_WIFI_STA);
        char macBuf[32];
        snprintf(macBuf, sizeof(macBuf), "NODE_%02X%02X%02X", mac[3], mac[4], mac[5]);
        deviceID = String(macBuf);
#endif
    }

    if (sensorTypeConfig == 0) {
        sensor = &sensorRM3100;
    } else if (sensorTypeConfig == 1) {
        sensor = &sensorFLC100;
    } else if (sensorTypeConfig == 2) {
        sensor = &sensorMock;
    }

    if (outputMode == MODE_BLE || outputMode == MODE_BOTH) {
        bleStream.begin(deviceID);
        delay(150); // Allow NimBLE BTDM controller memory allocation to complete cleanly before Wi-Fi init
        if (outputMode == MODE_BLE) {
            bleStream.powerDownModem();
        }
    }

    if (outputMode == MODE_WIFI || outputMode == MODE_BOTH) {
        if (wifiSSID.length() > 0) {
            connectWiFi();
        }
    } else {
        WiFi.mode(WIFI_OFF);
        wifiConnected = false;
    }
}

volatile uint32_t sampleCounter = 0;
float lastBmag_nT = 0.0f;

void sendOutputSample(const String &deviceID, uint64_t ts, float x, float y, float z, uint32_t status, const char *line, size_t len);

inline uint16_t getTelemetryStatusWord(uint32_t rawStatus = 0) {
    if (sensorTypeConfig == 2 || sensor == &sensorMock) {
        return STATUS_FLAG_MOCK;
    }
    if (sensorTypeConfig == 1) {
        return (uint16_t)(rawStatus & 0x7FFE) | STATUS_FLAG_FLC100;
    }
    if (sensorTypeConfig == 0) {
        return (uint16_t)(rawStatus & 0x7FFD) | STATUS_FLAG_RM3100;
    }
    return 0x0000;
}

void sendOutputSample(uint64_t ts, float x, float y, float z, uint32_t status = 0xC00000) {
    sampleCounter = sampleCounter + 1;
    lastBmag_nT = sqrtf(x * x + y * y + z * z);
    char line[160];
    uint32_t finalStatus = status;
    if (sensorTypeConfig == 2 || sensor == &sensorMock) {
        finalStatus = 0x800000 | STATUS_FLAG_MOCK;
    }
    float tC = (sensor != nullptr) ? sensor->readTemperatureC() : -999.0f;
    float tVal = (tC > -200.0f && tC < 200.0f) ? tC : 0.0f;
    int len = snprintf(line, sizeof(line), "%s,%llu,%.2f,%.2f,%.2f,%06X,%.1f,%.2f\n",
                       deviceID.c_str(), (unsigned long long)ts, x, y, z,
                       (unsigned int)(finalStatus & 0xFFFFFF), tVal, g_cachedBatteryVoltage);
    sendOutputSample(deviceID, ts, x, y, z, finalStatus, line, (size_t)len);
}


static TelemetryRingBuffer telemetryRingBuffer;
static uint8_t lastSentCount = 0;
static uint32_t nextBurstTxMs = 0;
static bool isTxActive = false;
static uint32_t txStartMs = 0;
static uint8_t txRetryCount = 0;
static uint32_t activeBurstDurationMs = 1000;

static bool isModemWarming = false;
static uint32_t warmupStartMs = 0;
const uint32_t BLE_WARMUP_MS = 150; // 150ms pre-burst warmup for RF PLL and baseband stabilization

#ifndef DEBUG_BLE_TX
#define DEBUG_BLE_TX 1 // Set to 0 (or pass -D DEBUG_BLE_TX=0 in platformio.ini) to disable TX debug prints
#endif

#if DEBUG_BLE_TX
  #define TX_DEBUG_PRINTF(...) Serial.printf(__VA_ARGS__)
#else
  #define TX_DEBUG_PRINTF(...) ((void)0)
#endif

void checkBleAckTask() {
    if (isTxActive) {
        bool acked = bleStream.isBatchAcked();
        uint32_t elapsed = millis() - txStartMs;
        uint32_t timeoutMs = activeBurstDurationMs + 100;
        if ((elapsed >= 250 && acked) || (elapsed >= timeoutMs)) {
            bleStream.stopAdvertising();
            bleStream.powerDownModem();
#if !defined(CONFIG_IDF_TARGET_ESP32C6) && !defined(ARDUINO_ARCH_ESP32C6)
            if (outputMode == MODE_BLE) {
                safeSetCpuFrequencyMhz(40);
            }
#endif
            isTxActive = false;
            isModemWarming = false;
            if (acked) {
                TX_DEBUG_PRINTF("[TX] Burst ACKED! Cleared %d samples.\n", lastSentCount);
                txRetryCount = 0;
                telemetryRingBuffer.confirmAck(lastSentCount);
            } else {
                txRetryCount++;
                TX_DEBUG_PRINTF("[TX] Burst NOT ACKED (timeout). Retry count: %d. Backlog: %d\n", txRetryCount, telemetryRingBuffer.getUnackedCount());
            }
            lastSentCount = 0;
        }
    }
}

void processBleTelemetry(const String &deviceID, uint64_t ts, float x, float y, float z, uint32_t status, const char *line) {
    // Insert new sample into circular buffer (3.0 hours capacity @ 1 Hz)
    uint32_t ts_ms = (uint32_t)(ts / 1000ULL);
    telemetryRingBuffer.push(ts_ms, x, y, z);
}

void checkBleBurstTransmission() {
    checkBleAckTask();

    if (!isTxActive && (outputMode == MODE_BLE || outputMode == MODE_BOTH)) {
        uint8_t targetBatchSize = (batchSizeConfig >= 1 && batchSizeConfig <= 18) ? batchSizeConfig : 10;
        uint32_t minBurstIntervalMs = (uint32_t)targetBatchSize * 1000UL;
        uint16_t unacked = telemetryRingBuffer.getUnackedCount();
        bool readyToSend = (unacked > 0 && (unacked >= targetBatchSize || !streaming));

        // Phase 1: Pre-burst Wakeup (150 ms lead time)
        // Re-enables the BLE controller and RF PLL so oscillators stabilize before packet transmission
        if (!isModemWarming && readyToSend && (millis() + BLE_WARMUP_MS >= nextBurstTxMs)) {
            safeSetCpuFrequencyMhz(80);
            bleStream.powerUpModem(deviceID);
            isModemWarming = true;
            warmupStartMs = millis();
        }

        // Phase 2: Transmit Burst once target time is reached and stabilization period has completed
        if (isModemWarming && (millis() >= nextBurstTxMs || (millis() - warmupStartMs >= BLE_WARMUP_MS))) {
            uint8_t countToPack = targetBatchSize;
            if (unacked > targetBatchSize) {
                countToPack = min((uint16_t)18, unacked);
            }

            SensorBatchPacket batch;
            uint8_t countToSend = telemetryRingBuffer.getBatch(batch, deviceID.c_str(), countToPack);
            if (countToSend > 0) {
                batch.status = getTelemetryStatusWord();
                batch.vbat_mv = sampleBatteryMilliVolts(); // Sample fresh ADC reading during burst wakeup
                float tC = (sensor != nullptr) ? sensor->readTemperatureC() : -999.0f;
                batch.temp_c_x100 = (tC > -200.0f && tC < 200.0f) ? (int16_t)roundf(tC * 100.0f) : 0x7FFF;

                bleStream.clearBatchAck();
                activeBurstDurationMs = (txRetryCount > 0) ? 2500 : BLEConfig::BURST_DURATION_MS;
                bleStream.notifyBatchBinary(batch, activeBurstDurationMs);
                lastSentCount = countToSend;

                // Drift-free periodic schedule on exact 10.0s grid
                nextBurstTxMs += minBurstIntervalMs;
                if (nextBurstTxMs <= millis() + BLE_WARMUP_MS) {
                    nextBurstTxMs = millis() + minBurstIntervalMs;
                }
                txStartMs = millis();
                isTxActive = true;
                isModemWarming = false;
            } else {
                bleStream.powerDownModem();
#if !defined(CONFIG_IDF_TARGET_ESP32C6) && !defined(ARDUINO_ARCH_ESP32C6)
                if (outputMode == MODE_BLE) {
                    safeSetCpuFrequencyMhz(40);
                }
#endif
                isModemWarming = false;
            }
        }
    }
}
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
void loop() {
    checkBleBurstTransmission();

#if defined(HELTEC_V4) || defined(ARDUINO_heltec_wifi_lora_32_V3)
    // Check USER/PRG button press (GPIO 0) to wake OLED screen
    static bool lastBtnState = HIGH;
    bool btnState = digitalRead(0);
    if (btnState == LOW && lastBtnState == HIGH) {
        lastOledActivityMs = millis();
        if (!oledScreenActive) {
            oledDisplay.displayOn();
            oledScreenActive = true;
        }
    }
    lastBtnState = btnState;

    // Auto-sleep OLED display after 10 seconds of inactivity (~20 mA power saving)
    if (millis() - lastOledActivityMs > 10000) {
        if (oledScreenActive) {
            oledDisplay.displayOff();
            oledScreenActive = false;
        }
    } else {
        if (!oledScreenActive) {
            oledDisplay.displayOn();
            oledScreenActive = true;
        }

        static uint32_t lastOledUpdateMs = 0;
        if (millis() - lastOledUpdateMs >= 500) {
            lastOledUpdateMs = millis();
            const char* modeNames[] = {"SERIAL", "WIFI", "BOTH", "BLE", "LORA"};
            oledDisplay.updateSensorScreen(
                deviceID.c_str(),
                sensor ? sensor->getSensorName().c_str() : "NONE",
                lastBmag_nT,
                sampleCounter,
                getBatteryVoltage(), // 0ms instantaneous read from cache
                modeNames[outputMode % 5]
            );
        }
    }
#endif

    // Fallback periodic refresh when unbatched streaming (batch_size == 1) or serial mode
    static uint32_t lastUnbatchedVbatMs = 0;
    if ((batchSizeConfig == 1 || outputMode == MODE_SERIAL) && (millis() - lastUnbatchedVbatMs >= 10000)) {
        lastUnbatchedVbatMs = millis();
        sampleBatteryVoltage();
    }

    // Low-power status LED pulse (crisp 20 ms flash every 10s instead of 50% continuous burn)
#if LED_PIN >= 0
    static unsigned long lastPulseStartMs = 0;
    static bool ledActive = false;
    unsigned long currentMillis = millis();

    if (ledActive && (currentMillis - lastPulseStartMs >= 20)) {
        digitalWrite(LED_PIN, LED_OFF);
        ledActive = false;
    } else if (!ledActive && (currentMillis - lastPulseStartMs >= 10000)) {
        lastPulseStartMs = currentMillis;
        digitalWrite(LED_PIN, LED_ON);
        ledActive = true;
    }
#endif

    // CLI Parsing
    serialCLI.update();

    // Hardware Watchdog: Detect DRDY interrupt stall due to physical bumps or power glitches
    static uint32_t lastWdCheckMs = 0;
    uint32_t nowWdMs = millis();
    if (streaming && sensor != NULL && sensorTypeConfig != 2 && (nowWdMs - lastWdCheckMs >= 500)) {
        lastWdCheckMs = nowWdMs;
        uint64_t nowUs = esp_timer_get_time();
        if (lastDrdyTimeUs > 0 && (nowUs - lastDrdyTimeUs > 500000ULL)) {
            recoverSensor();
        }
    }

    // WiFi UDP Command Listening & Low-Latency Batch Flushing
    if (wifiConnected) {
        if (udpBatchLen > 0 && (millis() - lastUdpFlushMs >= 50)) {
            flushUdpBatch();
        }

        int packetSize = udp.parsePacket();
        if (packetSize) {
            targetIP = udp.remoteIP(); // Auto-discover desktop app's IP address
            char buf[256];
            int len = udp.read(buf, 255);
            if (len > 0) {
                buf[len] = 0;
                String udpCmd = String(buf);
                udpCmd.trim();
                if (udpCmd.length() > 0) {
                    Serial.print("Executing UDP Command: ");
                    Serial.println(udpCmd);
                    serialCLI.handleCommand(udpCmd);
                }
            }
        }
    }

    // Data Streaming (Unified ring-buffer driven for all sensors)
    if (streaming && sensor != NULL) {
        float scaleFactor = sensor->getScaleFactor();
        ADCSample sample;
        while (sensor->popSample(sample)) {
            float x = (float)sample.x * scaleFactor;
            float y = (float)sample.y * scaleFactor;
            float z = (float)sample.z * scaleFactor;
            uint32_t status = sample.status;
            uint64_t ts = sample.ts;

            uint16_t decimationFactor = current_downsample;
            if (decimationFactor <= 1) {
                // Direct streaming without averaging
                sendOutputSample(ts, x, y, z, status);
            } else {
                static float sumX = 0, sumY = 0, sumZ = 0;
                static uint16_t decimationCounter = 0;

                sumX += x;
                sumY += y;
                sumZ += z;
                decimationCounter++;

                if (decimationCounter >= decimationFactor) {
                    float avgX = sumX / (float)decimationCounter;
                    float avgY = sumY / (float)decimationCounter;
                    float avgZ = sumZ / (float)decimationCounter;

                    sumX = 0;
                    sumY = 0;
                    sumZ = 0;
                    decimationCounter = 0;

                    sendOutputSample(ts, avgX, avgY, avgZ, status);
                }
            }
        }
    }

    // Yield to FreeRTOS IDLE task to enable automatic dynamic CPU clock gating
    vTaskDelay(pdMS_TO_TICKS(1));
}

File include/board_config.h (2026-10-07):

#ifndef BOARD_CONFIG_H
#define BOARD_CONFIG_H

#include <Arduino.h>

#if defined(HELTEC_V4) || defined(ARDUINO_heltec_wifi_lora_32_V3)
// Heltec WiFi LoRa 32 V3 / V4 (ESP32-S3 + SX1262)
#define BOARD_NAME   "Heltec WiFi LoRa 32 V4 (ESP32-S3)"
#define BOARD_HAS_LORA 1
#define SCK_PIN      41
#define MOSI_PIN     42
#define MISO_PIN     40
#define DRDY_PIN     38
#define CS_PIN       39
#define LED_PIN      35
#define LED_ON       HIGH
#define LED_OFF      LOW
#define VEXT_PIN     36

// LoRa Radio Pins for Heltec V4
#define LORA_CS_PIN   8
#define LORA_DIO1_PIN 14
#define LORA_RST_PIN  12
#define LORA_BUSY_PIN 13
#define LORA_SCK_PIN  9
#define LORA_MOSI_PIN 10
#define LORA_MISO_PIN 11

// Heltec V4 Front-End Module (FEM: GC1109 / KCT8103L) Control Pins
#define LORA_FEM_PWR_PIN  7   // VFEM_Ctrl (Active-HIGH: enables 3.3V power via TLV75733 LDO)
#define LORA_FEM_CSD_PIN  2   // PA_CSD (Active-HIGH: enables FEM LNA/PA out of shutdown)
#define LORA_FEM_CPS_PIN  46  // PA_CPS (Power select: High = +30dBm PA mode, Low = Bypass)
#define LORA_FEM_CTX_PIN  5   // PA_CTX (V4.3 KCT8103L: LOW = RX LNA mode, HIGH = TX mode)

#elif defined(XIAO_S3_WIO_SX1262) || defined(ARDUINO_XIAO_ESP32S3)
// Seeed Studio XIAO ESP32-S3 + Wio-SX1262 Mezzanine Board
#define BOARD_NAME   "Seeed Studio XIAO ESP32-S3 + Wio-SX1262"
#define BOARD_HAS_LORA 1
#ifndef LORA_TX_POWER_DBM
#define LORA_TX_POWER_DBM 2 // +2 dBm for bench testing to avoid saturating Heltec V4 LNA at <1m
#endif

// Sensor SPI Pins (XIAO D8=SCK, D9=MISO, D10=MOSI)
#define SCK_PIN      7
#define MOSI_PIN     9
#define MISO_PIN     8
#define CS_PIN       4   // D3 (GPIO4)
#define DRDY_PIN     3   // D2 (GPIO3)
#define LED_PIN      21  // User LED on XIAO ESP32-S3 (Active-LOW)
#define LED_ON       LOW
#define LED_OFF      HIGH
#define VBAT_ADC_PIN 1   // GPIO1 (D0 / A0) for Battery ADC
#define VBAT_DIVIDER_RATIO 2.0f

// LoRa Radio Pins for Seeed Wio-SX1262 (40-pin B2B mezzanine connector)
#define LORA_CS_PIN        41
#define LORA_DIO1_PIN      39
#define LORA_RST_PIN       42
#define LORA_BUSY_PIN      40
#define LORA_RF_SWITCH_PIN 38
#define LORA_SCK_PIN       7
#define LORA_MISO_PIN      8
#define LORA_MOSI_PIN      9
#define LORA_TCXO_VOLTAGE  1.8f

#elif defined(CONFIG_IDF_TARGET_ESP32C6) || defined(ARDUINO_ARCH_ESP32C6)
// Seeed Studio XIAO ESP32-C6 Pinout (in Supermini carrier socket)
#define BOARD_NAME   "Seeed Studio XIAO ESP32-C6"
#define SCK_PIN      1   // SCLK
#define MOSI_PIN     2   // MOSI
#define CS_PIN       23  // CS
#define MISO_PIN     19  // MISO
#define DRDY_PIN     20  // nDRDY
#define LED_PIN      15  // Yellow User LED on XIAO ESP32-C6 (Active-LOW)
#define LED_ON       LOW
#define LED_OFF      HIGH
#define VBAT_ADC_PIN 0   // GPIO0 (ADC1_CH0) for Battery Voltage Divider
#define VBAT_DIVIDER_RATIO 2.0f // Factor of 2 voltage divider

#elif defined(CONFIG_IDF_TARGET_ESP32C3) || defined(ARDUINO_ARCH_ESP32C3)
// ESP32-C3 Supermini Pinout
#define BOARD_NAME   "ESP32-C3 Supermini"
#define SCK_PIN      6
#define MOSI_PIN     7
#define MISO_PIN     2
#define DRDY_PIN     3
#define CS_PIN       10
#define LED_PIN      8   // Blue User LED on ESP32-C3 Supermini (Active-LOW)
#define LED_ON       LOW
#define LED_OFF      HIGH
#define VBAT_ADC_PIN 4   // GPIO4 (ADC1_CH4) for Battery Voltage Divider
#define VBAT_DIVIDER_RATIO 2.0f // Factor of 2 voltage divider

#else
// Legacy ESP32 Dev Module Pinout [DEPRECATED]
#define BOARD_NAME   "Legacy ESP32 Dev Module (WROOM)"
#define SCK_PIN      18
#define MISO_PIN     19
#define MOSI_PIN     23
#define CS_PIN       5
#define DRDY_PIN     4
#define LED_PIN      2
#define LED_ON       HIGH
#define LED_OFF      LOW
#endif

#define RESET_PIN   -1

#if defined(HELTEC_V4) || defined(ARDUINO_heltec_wifi_lora_32_V3)
// Battery Measurement Pins for Heltec WiFi LoRa 32 V3 / V4 (ESP32-S3)
#define VBAT_ADC_PIN   1
#define VBAT_CTRL_PIN  37
#define VBAT_DIVIDER_RATIO 4.90f // 390k / 100k divider + P-FET drop compensation (4.90x)
#endif

// Global battery cache
extern float g_cachedBatteryVoltage;

/**
 * @brief Measures real battery voltage via ADC and updates global cache.
 *        Should be called during the 10-second radio burst wake window.
 */
inline float sampleBatteryVoltage(bool force = false) {
    static uint32_t lastSampleMs = 0;
    uint32_t now = millis();

    // Only perform physical ADC conversion once every 60 seconds (~every 6 batches)
    if (!force && lastSampleMs > 0 && (now - lastSampleMs < 60000)) {
        return (g_cachedBatteryVoltage > 0.0f) ? g_cachedBatteryVoltage : 0.0f;
    }
    lastSampleMs = now;
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

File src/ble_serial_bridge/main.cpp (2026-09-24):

#include <Arduino.h>
#include <NimBLEDevice.h>
#include "board_config.h"
#include "TelemetryPacket.h"

// Supermini ESP32-C3 Status LED
#ifndef LED_PIN
#define LED_PIN 8
#endif
#ifndef LED_ON
#define LED_ON LOW
#endif
#ifndef LED_OFF
#define LED_OFF HIGH
#endif

static unsigned long g_lastLedOnMs = 0;
static volatile bool g_ledState = false;
static uint32_t g_rxPacketCount = 0;
static uint8_t g_lastSeq = 255;
static uint64_t g_lastTimestampUs = 0;

void triggerLed() {
    digitalWrite(LED_PIN, LED_ON);
    g_lastLedOnMs = millis();
    g_ledState = true;
}

static bool isValidNodeId(const char* id) {
    if (!id || id[0] == '\0') return false;
    size_t len = 0;
    for (size_t i = 0; i < 8 && id[i] != '\0'; i++) {
        char c = id[i];
        if (!isalnum((unsigned char)c) && c != '_' && c != '-') return false;
        len++;
    }
    return len >= 3;
}

class BridgeScanCallbacks : public NimBLEScanCallbacks {
    void onResult(const NimBLEAdvertisedDevice* advertisedDevice) override {
        std::string manuData = advertisedDevice->getManufacturerData();
        size_t mlen = manuData.length();
        if (mlen < 26) return;

        const uint8_t* raw = (const uint8_t*)manuData.data();
        int rssi = advertisedDevice->getRSSI();

        // ---------------------------------------------------------------------
        // 1. Gateway 1M Extended Advertising Telemetry Broadcast (GatewayAdvPacket)
        // Magic bytes "MG" at offset 0 (if company ID stripped) or offset 2 (if 0xFFFF prefixed)
        // ---------------------------------------------------------------------
        int mgOffset = -1;
        if (mlen >= 27 && raw[0] == 'M' && raw[1] == 'G') {
            mgOffset = 0;
        } else if (mlen >= 29 && raw[0] == 0xFF && raw[1] == 0xFF && raw[2] == 'M' && raw[3] == 'G') {
            mgOffset = 2;
        }

        if (mgOffset >= 0) {
            const uint8_t* p = raw + mgOffset;
            size_t availableLen = mlen - mgOffset;

            uint8_t seq = p[2];
            char nodeId[9] = {0};
            memcpy(nodeId, p + 3, 8);

            uint64_t timestamp_us;
            memcpy(&timestamp_us, p + 11, sizeof(uint64_t));

            // Deduplicate repeat broadcasts of the exact same batch
            if (seq == g_lastSeq && timestamp_us == g_lastTimestampUs) {
                return;
            }
            g_lastSeq = seq;
            g_lastTimestampUs = timestamp_us;

            uint16_t sample_interval_ms;
            memcpy(&sample_interval_ms, p + 19, sizeof(uint16_t));
            if (sample_interval_ms == 0) sample_interval_ms = 1000;

            uint8_t sample_count = p[21];
            uint16_t status;
            memcpy(&status, p + 22, sizeof(uint16_t));

            uint16_t vbat_mv;
            memcpy(&vbat_mv, p + 24, sizeof(uint16_t));
            float vbat = (float)vbat_mv / 1000.0f;

            size_t expected_samples_bytes = (size_t)sample_count * sizeof(CompactSample);
            size_t raw_header_len = (sample_count > 0 && availableLen >= expected_samples_bytes)
                                    ? (availableLen - expected_samples_bytes)
                                    : availableLen;

            float temp = 0.0f;
            int8_t node_rssi = 0;
            uint16_t gw_vbat_mv = 0;
            size_t headerSize = 27;

            // Dynamically determine header size:
            // Revision 3 (current, with thermistor temp_c_x100 and gw_vbat_mv): 31 bytes
            // Revision 2 (with gw_vbat_mv, no thermistor): 29 bytes
            // Revision 1 (legacy, no gw_vbat_mv, no thermistor): 27 bytes
            if (raw_header_len >= 31) {
                int16_t temp_c_x100;
                memcpy(&temp_c_x100, p + 26, sizeof(int16_t));
                temp = (temp_c_x100 != 0x7FFF) ? (float)temp_c_x100 / 100.0f : 0.0f;
                node_rssi = (int8_t)p[28];
                memcpy(&gw_vbat_mv, p + 29, sizeof(uint16_t));
                headerSize = 31;
            } else if (raw_header_len >= 29) {
                temp = 0.0f;
                node_rssi = (int8_t)p[26];
                memcpy(&gw_vbat_mv, p + 27, sizeof(uint16_t));
                headerSize = 29;
            } else {
                temp = 0.0f;
                node_rssi = (int8_t)p[26];
                gw_vbat_mv = 0;
                headerSize = 27;
            }
            float gw_vbat = (float)gw_vbat_mv / 1000.0f;

            triggerLed();
            g_rxPacketCount++;

            if (sample_count == 0) {
                // Heartbeat packet from gateway
                Serial.printf("# [HEARTBEAT] ID: %s | Battery: %.2fV | Seq: %u | RSSI: %d dBm\n",
                              nodeId, gw_vbat > 0 ? gw_vbat : vbat, seq, rssi);
                return;
            }

            // Emit each sample as standard 10-column CSV
            for (uint8_t i = 0; i < sample_count; i++) {
                size_t sampleOffset = mgOffset + headerSize + (i * sizeof(CompactSample));
                if (sampleOffset + sizeof(CompactSample) > mlen) break;

                float x, y, z;
                memcpy(&x, raw + sampleOffset, sizeof(float));
                memcpy(&y, raw + sampleOffset + 4, sizeof(float));
                memcpy(&z, raw + sampleOffset + 8, sizeof(float));

                uint64_t offset_us = (uint64_t)(sample_count - 1 - i) * (uint64_t)sample_interval_ms * 1000ULL;
                uint64_t sample_ts = (timestamp_us >= offset_us) ? (timestamp_us - offset_us) : 0;

                // Standard telemetry CSV format (10-column):
                // node_id,timestamp_us,x_nT,y_nT,z_nT,status_hex,temp,vbat,rssi,gw_vbat
                Serial.printf("%s,%llu,%.2f,%.2f,%.2f,%04X,%.2f,%.2f,%d,%.2f\n",
                              nodeId,
                              (unsigned long long)sample_ts,
                              x, y, z,
                              status,
                              temp,
                              vbat,
                              (int)node_rssi,
                              gw_vbat);
            }
            return;
        }
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

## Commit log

2026-06-16 fix: sample rate selection for rm3100s
    [main.cpp, main.py, serial_worker.py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]
2026-06-30 added FLC100 PCB
    [FLC100_pcb.kicad_pcb, FLC100_pcb.kicad_sch, bom.csv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]
2026-07-02 remove unneded files
    [bridge_sensor.kicad_sch, untitled.kicad_sch]
2026-07-14 minor updates for new PCB board
2026-07-14 add 2.048MHz clock on pin 27
2026-07-24 recover tempoary data file
    [FLC100_pcb.kicad_pcb, FLC100_pcb.kicad_sch, bom.csv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]
2026-07-27 FLC100 runnin on PCB v0.1, but still got some scaling issues
    [CLI.cpp, main.cpp, main.py]
2026-08-03 autodetect sensor type now working
2026-08-08 fix gateway, provision_node script. timestamping at the gatwway
    [gateway.py, main.cpp, provision_node.py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]
2026-08-09 add possibile extra 3 metadata columns (temperature, Vbat, rssi)
2026-08-10 cleaned up board configs; Added testing docs.
2026-08-20 termux usb device names
2026-08-25 more LoRa power saving. Script updates
2026-09-09 Refactor receiver architecture into modular subsystems and improve BLE catch-up reliability
    - Modularize receiver into distinct components:
    - BLEReceiver, ESPNowReceiver, LoRaReceiver, UDPReceiver
    - IngestionPipeline, NodeTracker, RendezvousScheduler
    - BLEEgress, RelayEgress, PowerManager, ReceiverCLI
    - Improve BLE gateway catch-up buffering and packet ingestion handling
    - Organize docs into numbered guides and archive legacy documentation
    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
2026-09-09 Implement BLE hardware modem power-cycling and 150ms pre-burst warmup for sensor nodes
    - Power down Bluetooth baseband controller (esp_bt_controller_disable) between bursts to drop idle current from ~30mA to ~10-12mA
    - Introduce 150ms pre-burst lead time to allow RF PLL and NimBLE stack to stabilize before Coded PHY Extended Advertising bursts
    - Preserve backlog catch-up expansion (up to 18 samples) and ACK handling
    - Update platformio.ini to exclude power_test from heltec_v4_sensor build
    [main.cpp]
2026-09-10 Fix BLEStream deinit parameter to maintain heap stability
    - Use NimBLEDevice::deinit(false) to prevent freeing static singleton structures
    - Add *.lck to .gitignore for KiCad lock files
2026-09-10 fix(sensor): stabilize SPI init, FreeRTOS priority, and C6 80MHz floor for FLC100
    [CLI.cpp, configure_profile.py, main.cpp]
2026-09-10 docs: add implementation plan for ADC Channel 4 thermistor logging
2026-09-10 feat(receiver): add battery voltage sampling on GPIO4 (ADC1_CH4) and status CLI reporting
2026-09-10 feat(telemetry): report gateway battery in ble_gateway banners and heartbeats
2026-09-10 fix(central_service,ble_gateway): normalize telemetry ingestion, batch forwarding, and mock badge display
    [gateway.py, server.py]
2026-09-10 feat(dashboard): show node and gateway battery voltage, add battery chart and live stats
2026-09-11 PCB tweaks
2026-09-12 perf(server,firmware): optimize central server queries and resolve ADS131 SPI spikes
    - Central Server & Dashboard:
    - Cache record_count in nodes table to eliminate correlated full-index COUNT(*) scans on /api/v1/nodes
    - Use executemany and single node update per batch in /api/v1/telemetry/batch
    - Add default limit and index-accelerated DESC query to /api/v1/data
    - Bound dashboard history query to limit=100 and increase poll interval to 30s
    - Firmware (FLC100 & ESP32):
    - Migrate ADS131E08 SPI read to 8 MHz hardware FIFO block transfer (27 us vs 300 us)
    - Synchronize DFS CPU frequency switches with SPI critical section (safeSetCpuFrequencyMhz)
    - Add single-sample jump glitch rej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
    [configure_profile.py, main.cpp, server.py]
2026-09-13 feat(telemetry): implement ADS131E08 CH5 thermistor measurement and relay pipeline
2026-09-13 fix(gateway): eliminate out-of-range float NaN serialization errors and prevent infinite retry loops
    [gateway.py, stream_parser.py]
2026-09-17 fix(ble_gateway): dynamically compute header offset for GatewayAdvPacket to fix float misalignment with temp field
    [gateway.py]
2026-09-17 feat(bridge): add ESP32-C3 BLE-to-serial bridge and serial support in ble_gateway
    - Add ESP32-C3 Supermini firmware (src/ble_serial_bridge/main.cpp) to decode BLE 1M Extended Advertising batches (GatewayAdvPacket), node batches (SensorBatchPacket), and legacy packets (SensorBinary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
    - Add PlatformIO environment esp32c3_ble_bridge and update build filters across targets
    - Add --serial and --baud support to scripts/ble_gateway.py to ingest from hardware bridges
    - Ignore .env_* files in .gitignore to protect local credentials
2026-09-17 Fix receiver slotted rendezvous timing, add BLE diagnostics, and audit docs
    - Decouple nominal burst cadence from sample_count in NodeTracker to prevent backlog sync loss
    - Add immediate discovery mode exit upon first valid batch capture to eliminate 12s high-current burns
    - Lock receiver scanner to dedicated Coded PHY (SCAN_CODED) for reliable RX and hardware AUX_SCAN_REQ ACKs
    - Increase rendezvous lead time margin to 350ms to absorb uncalibrated crystal drift
    - Add BLE Extended Advertising diagnostic packets and decoder in ble_gateway.py
    - Disable USB-CDC on boot for SUPERMINI_GATEWAY profile to eliminate USB PHY idle drain
    - Audit documentation: fix broken legacy links, update pinouts, an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
    [BLEEgress.cpp]
2026-09-17 fix(timing): Add NodeEpochTracker to preserve accurate historical timestamps during backlog catch-up
    [gateway.py, stream_parser.py]
2026-09-17 fix(scripts): Skip serial CLI configuration on SUPERMINI_GATEWAY to prevent USB-CDC hang
    [configure_profile.py]
2026-09-18 fix(power): Restore Bluetooth controller power-gating to achieve 10mA sleep current
    - Re-enable esp_bt_controller_disable() and NimBLEDevice::deinit(false) during slotted rendezvous sleep
    - Re-enable esp_bt_controller_enable(ESP_BT_MODE_BLE) on 350ms lead window wakeup
    - Verified on bench hardware power meter: inactive current drops from 32mA to 10mA with 100% burst ACKs maintained
    - Document requirement in AI.md and docs/2_FIRMWARE_AND_POWER_GUIDE.md
2026-09-18 refactor(scripts): Replace legacy ble_monitor.py with modern ble_monitor.py
    - Remove obsolete legacy ble_monitor.py (old 26-byte 1-sample packet reader)
    - Move scripts/ble_gateway.py to scripts/ble_monitor.py to clearly distinguish it from central_service/gateway.py
    - Update CLI docstrings and usage instructions in ble_monitor.py
    - Update all documentation references across AI.md, docs/, and central_service/
    [ble_monitor.py]
2026-09-18 Fix BLE bridge header offset misalignment, restore temp and preserve gateway battery in 10-column CSV stream
    [ble_monitor.py, gateway.py, main.cpp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]
2026-09-18 Improve BLE bridge and serial monitor filtering against foreign BLE noise
    [ble_monitor.py, main.cpp]
2026-09-18 Optimize gateway power: 120ms egress broadcast, 250ms rendezvous lead time, and idle discovery duty-cycling
2026-09-18 feat(profile): Add LAB_BENCH profile for 100 Hz USB Serial GUI bench measurements
2026-09-18 fix(configure_profile): Allow sufficient delay for SENSOR hardware probe and stabilization
    [configure_profile.py]
2026-09-23 fix(export): enable full telemetry export without 5k cap, add date/scope controls, and fix Parquet/NPZ
    [server.py, test_server.py]
2026-09-23 fix(chart): resolve NaN JSON serialization crash in downsampling and expand chart historical ranges
    [server.py, test_server.py]
2026-09-24 feat(receiver): enhance dual-PHY BLE bridge, safe 8-char node IDs, and 2-stage adaptive discovery backoff
2026-09-24 fix(firmware): resolve RM3100 SPI concurrency, interrupt watchdog, and 8-character node ID handling
    [CLI.cpp, main.cpp]
2026-09-30 feat(profile): add LYNEHAM1 profile for ESP32-C3 Supermini with RM3100 USB serial egress
2026-10-03 test: reorganize hardware tests, fix unittest discovery, and update environment dependencies
    [test_hardware.py]
2026-10-05 fix(receiver): read hardware eFuse MAC address via esp_read_mac
    [WiFiManager.cpp]
2026-10-07 fix(lora, wifi): correct SX1262 RSSI calculation, FEM LNA bypass, and Wi-Fi EAP handling
    - Correct SX1262 packet status reading (Opcode 0x14) and RSSI conversion (-RssiPkt / 2 dBm)
    - Configure Heltec V4.3 FEM (KCT8103L) bypass mode on GPIO 5 to prevent LNA desk saturation
    - Add xiao_s3_sx1262_sensor platformio target with board configuration
    - Improve Wi-Fi manager with EAP identity/user commands, backspace handling, and reconnect logic
    - Keep CPU clock above 40 MHz in PowerManager when Wi-Fi egress is active
    - Add detailed request validation error handling in FastAPI central server
    [CLI.cpp, HttpBatchEgress.cpp, ReceiverCLI.cpp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]
2026-10-07 feat(receiver): configure ROOF profile for LoRa-only RX and USB Serial CDC egress
    - Optimize heltec_v4_receiver firmware with -D LORA_ONLY_RECEIVER to disable 2.4 GHz NimBLE scan, ESP-NOW, and UDP receivers
    - Fully power off 2.4 GHz Wi-Fi and Bluetooth modems (WiFi.mode(WIFI_OFF), btStop()) on receiver in SERIAL egress mode to minimize power
    - Update ROOF profile in scripts/configure_profile.py to MODE SERIAL and reflect ~20-25 mA consumption
    - Update docs/ROOF_BENCH_TESTING_GUIDE.md to document pure LoRa RF + USB Serial CDC pipeline
    - Add CLI POWER command and runtime LoRa TX power configuration up to +20 dBm
    - Flash and verify live 1 Hz, 10-sample LoRa packet reception on /dev/ttyACM1 from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
2026-10-07 fix(lora): enable Heltec V4 FEM PA on transmit and back off SX1262 drive to 0 dBm
    - Power on FEM 3.3V LDO (GPIO 7) and wake FEM (GPIO 2) with 2 ms delay prior to transmission in LoRaStream::transmit()
    - Set default SX1262 drive power to 0 dBm for Heltec V4 so that ~20 dB FEM PA gain produces a clean, linear +20 dBm EIRP
    - Bench verification confirms RSSI improved by ~20 dB (from -52 dBm up to -32 dBm at ~1m)
2026-10-11 refactor(config): extract SensorConfig to decouple CLI and main
2026-10-11 refactor(sensor): extract SensorManager to centralize hardware probing, acquisition task, and watchdog
2026-10-11 refactor(architecture): decouple CLI/networking and encapsulate decimation in SensorManager
2026-10-13 fix(springbank): resolve cold boot DRDY latch deadlock, add TI t_SDECODE delay, disable USB-CDC for low power
2026-10-27 feat(gateway): add multi-serial ingestion and dynamic USB auto-discovery
    - Implement serial_device_worker and serial_manager_thread in gateway.py
    - Support dynamic auto-discovery of USB/CDC serial devices (Linux, macOS, Windows)
    - Support comma/space/semicolon delimited port lists in SERIAL_PORT and CLI arguments
    - Add thread-safe RLock synchronization to NodeEpochTracker in stream_parser.py
    - Add comprehensive automated unit test suite in test/test_gateway_multi_serial.py
    - Update .env.example and AI.md documentation
